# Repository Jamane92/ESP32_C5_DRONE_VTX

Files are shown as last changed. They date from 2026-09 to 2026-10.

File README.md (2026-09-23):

# ESP32_C5_DRONE_VTX

Ce projet à été réalisé individuellement en parallèle de mes études. C'est un module d'émission vidéo en digital à bas coût. Souhaitant me challenger dans mon parcours d'apprentissage en conception hardware, je me suis lancé le défi de construire un drone moi même, avec en première étape de ce gros projet, de faire un VTX ainsi qu'un Flight Controler (FC) de A à Z. Le projet Flight Controler est disponible sur cette page : https://github.com/Jamane92/Flight_Controler_STM32F405RGT6. 

Qu'est ce qu'un module VTX ? C'est un module d'émission vidéo, qui permet de transmettre la vue à la première personne du drone sur un écran au sol, que ce soit un téléphone ou un ordinateur par exemple. Cela permet de repérer le drone dans l'espace et de le faire voler à des endroits où nous ne pouvons pas voir. Un set complet bas/milieu de gamme coùute aux alentours de 200 à 250€. Ca fait mal. J'ai donc décidé, pour m'apprendre à implémenter une chip ESP32 sur PCB, de faire un PCB custom qui intègre une ESP32-C5-WROOM-1U-N8R8, une OV5640 ainsi qu'une carte SD, pour la somme ≈ 40€. Ce qui est un prix imbattable, tout simplement.

Le but de se projet est simple : d'un point de vue technique, m'apprendre à router des SoC (System On Chip) ainsi que des signaux critiques comme ceux de la caméra OV5640, le tout sur mon premier PCB 4 couches avec des composants SMD. Un grand pas donc depuis mon premier PCB sur mon robot équilibriste (https://github.com/Jamane92/Self_Balancing_Robot). Plus de détail dans les rubriques sur les choix de design (notamment sur des améliorations possibles).

Voilà à quoi ressemble le module : 
<p align="center">
vtx
</p>

Plus en détail, le coeur au milieu, à gauche l'antenne Lollipop et à droite la caméra. Ce PCB à fonctionné du premier coup. Voici à quoi ressemble l'interface WEB : 
<p align="center">
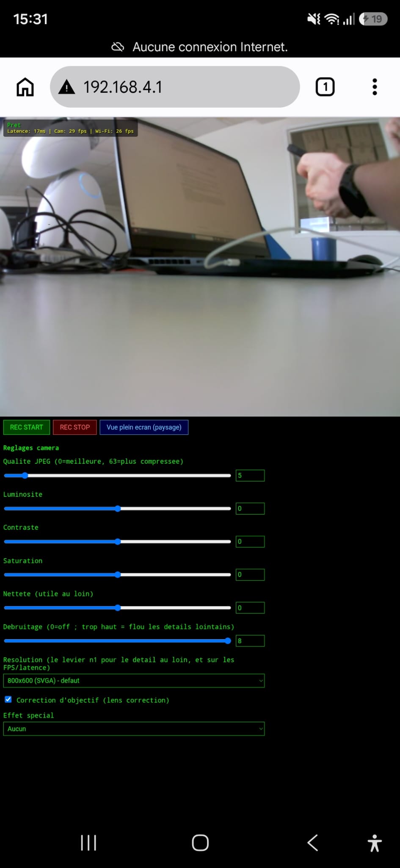
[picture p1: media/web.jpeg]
  
</p>

Voici un petit exemple de ce dont il est capable (entre autres : réglage de a qualité vidéo, compression, luminosité, saturation, contraste, filtre, enregistrement sur la SD Card) :

Voici une vidéo de mon balcon, au 3ème étage, avec l'exploration de tous les settings de la caméra : 

Voici une vidéo de moi en HVGA (480 × 320), gardez à l'esprit que l'on filmera en SVGA (800 × 600), soit littéralement 3 fois plus de pixels. 
<p align="center">
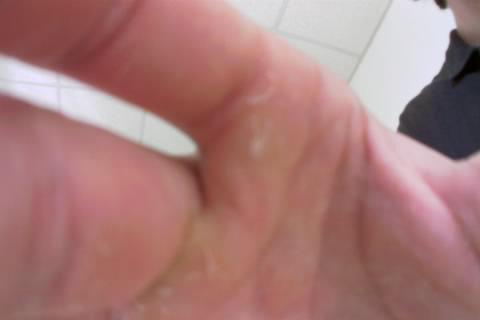
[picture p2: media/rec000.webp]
  
</p>

Pour la démo en vol, il faudra attendre que le projet du flight controler (https://github.com/Jamane92/Flight_Controler_STM32F405RGT6) soit terminé. 

Pour voir les performances du montage, voir le folder dedié.

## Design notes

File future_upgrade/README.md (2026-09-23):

Pour pénétrer des environnements denses (bâtiments, forêts), l'amélioration envisagée est matérielle : ajouter un **amplificateur de signal (LNA/PA)** entre l'ESP32 et l'antenne Lollipop.

L'impact de l'augmentation des Watts : Augmenter la puissance TX (par exemple passer de 50 mW à 1 Watt) n'empêche pas le signal d'être bloqué par un obstacle, mais lui donne une "force de frappe" bien supérieure. Si un mur absorbe -15 dBm du signal, un signal partant à +30 dBm (1 Watt) traversera le mur en conservant +15 dBm de l'autre côté, permettant à la puce RTL8812Au de continuer à recevoir le flux vidéo sans coupure.

Voici un exemple d'amplificateur avec un gain de 20 dB, de 28mm x 23mm :

<p align="center">
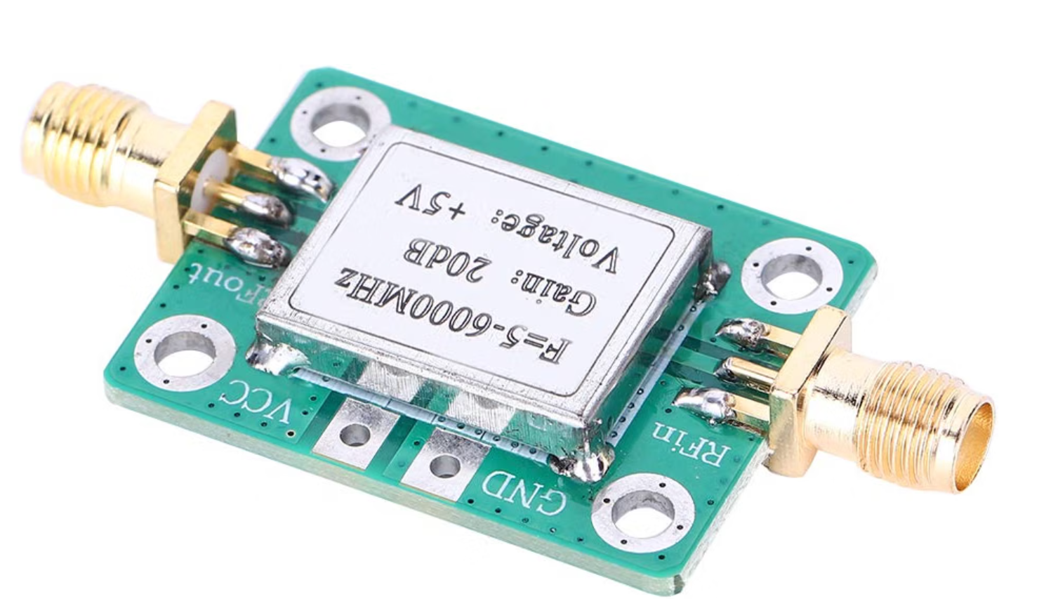
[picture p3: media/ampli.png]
Schématique

</p>

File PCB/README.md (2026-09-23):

Ce PCB contient **4 couches**, étant embarqué sur un drone, il possède des entrées d'alimentations **+5V**, que sont l'**USB-C**, également utilisé pour programmer l'**ESP32**, ainsi que des PADs de cuivre, qui viendront directement être branché à partir de mon flight controler. Il possède deux diodes Schottky pour faire du **OR'ing**. Une **OV5640**, un lecteur de **carte SD**, ainsi qu'un **module 1U** spécialement choisi pour la possibilité d'y brancher une **antenne**, qui est une **lollipop** en RHCP, mieux qu'une antenne "simple", car celle-ci émettra un signal en forme de cercle, parfaitement adapté pour une antenne en hauteur qui va communiquer avec le sol.

Je suis parti sur un **4 couches** pour me simplifier la vie. Mon stack-up est le suivant : 

  - L1 : SIGNAL
  - L2 : GND
  - L3 : GND
  - L4 : SIGNAL/POWER

Tous les composants sont sur la même face pour des raisons économiques (plus cher de faire les deux face lors de l'assemblage chez JLCPCB). 

Afin d'optimiser l'**intégrité des signaux**, de nombreux vias de masse (ground vias) ont été placés pour relier **(stitching)** les plans de masse entre les couches L2 et L3. Ce **stitching de masse assure un chemin de retour court**, direct et ininterrompu pour les signaux numériques à haute vitesse (bus de la caméra OV5640, interface de la carte SD) ainsi que pour la section RF à 5.8 GHz. Cela permet de **minimiser l'inductance des boucles de courant** et de **réduire drastiquement les interférences électromagnétiques** (EMI), un point absolument **critique** dans l'environnement très bruyant d'un drone (ESC, moteurs). 

L'**impédance** de la ligne de communication différentiel D+/D- est **matché à 90Ω**

Voici la schématique : 
<p align="center">
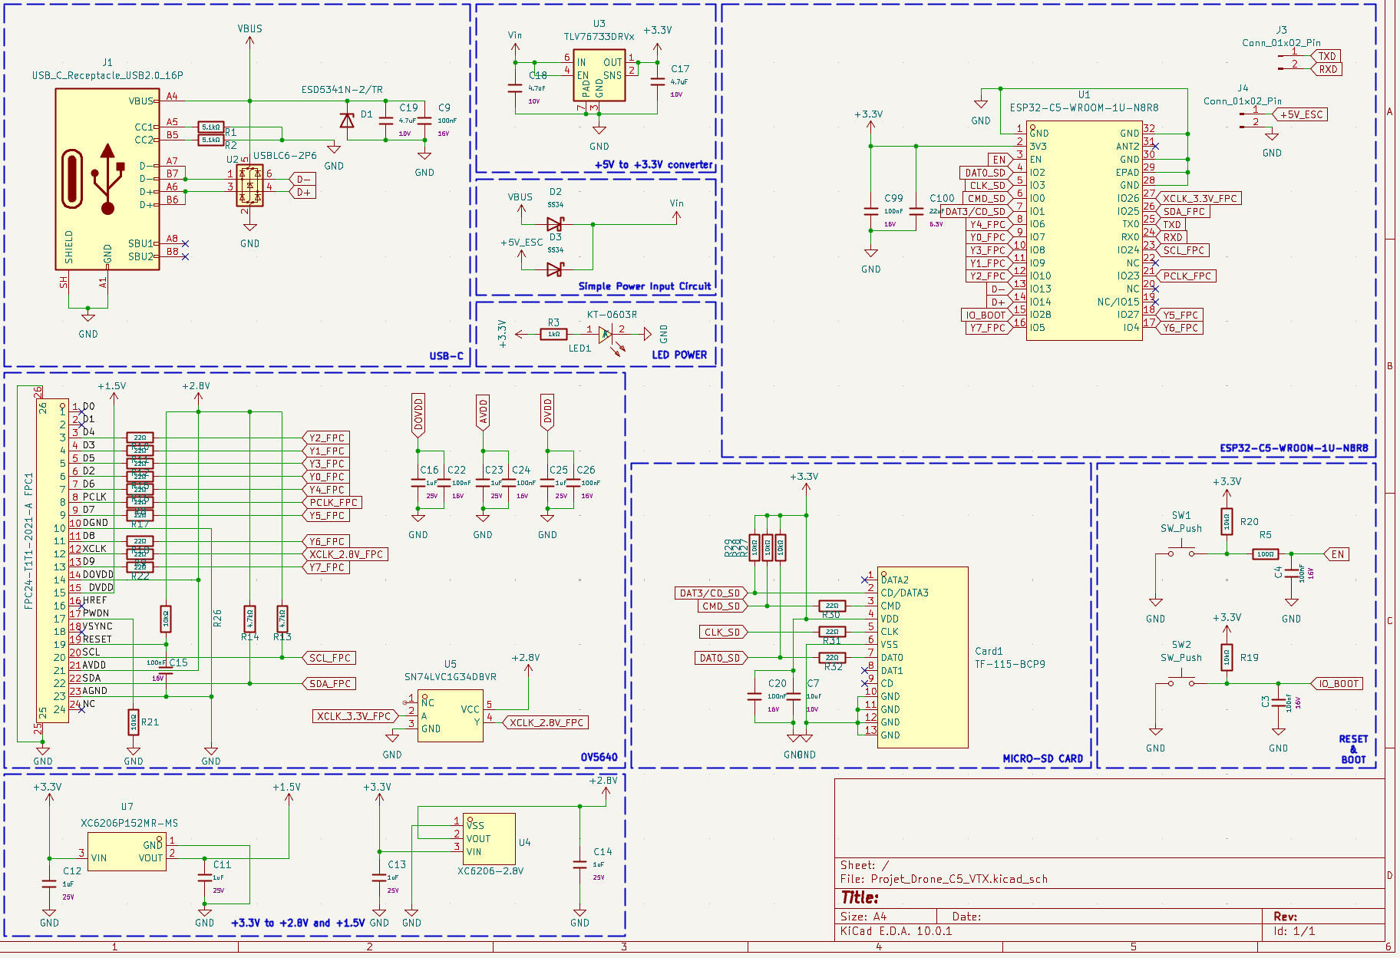
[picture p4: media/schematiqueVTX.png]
Schématique

</p>

Voici le routage : 
<p align="center">
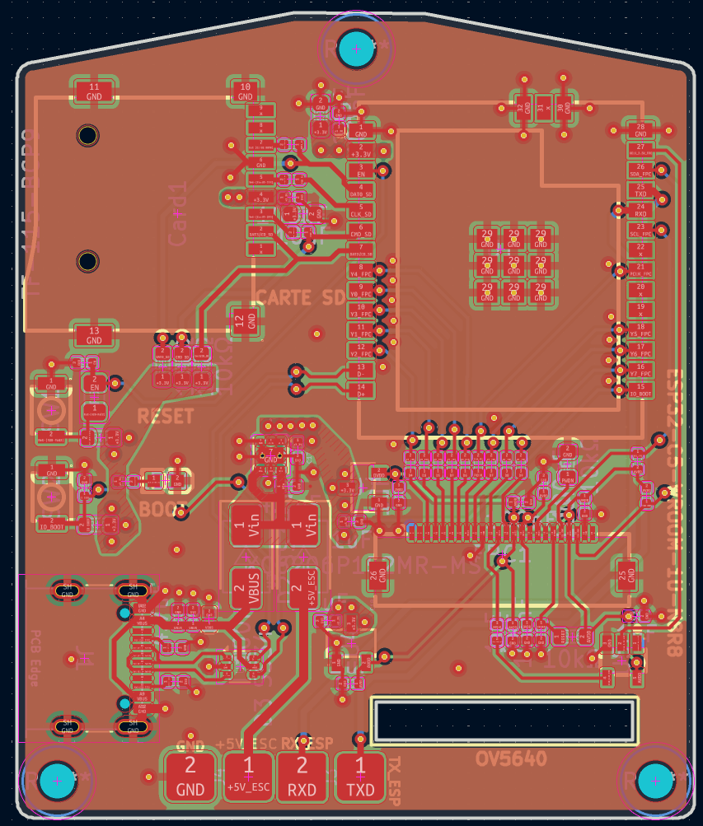
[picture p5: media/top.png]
top

</p>
<p align="center">
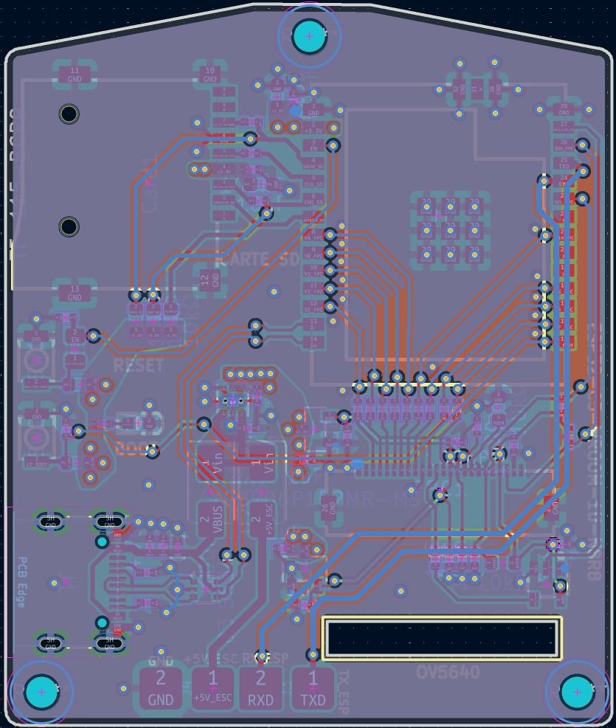
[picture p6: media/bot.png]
bot

</p>

Voici la 3D : 
<p align="center">
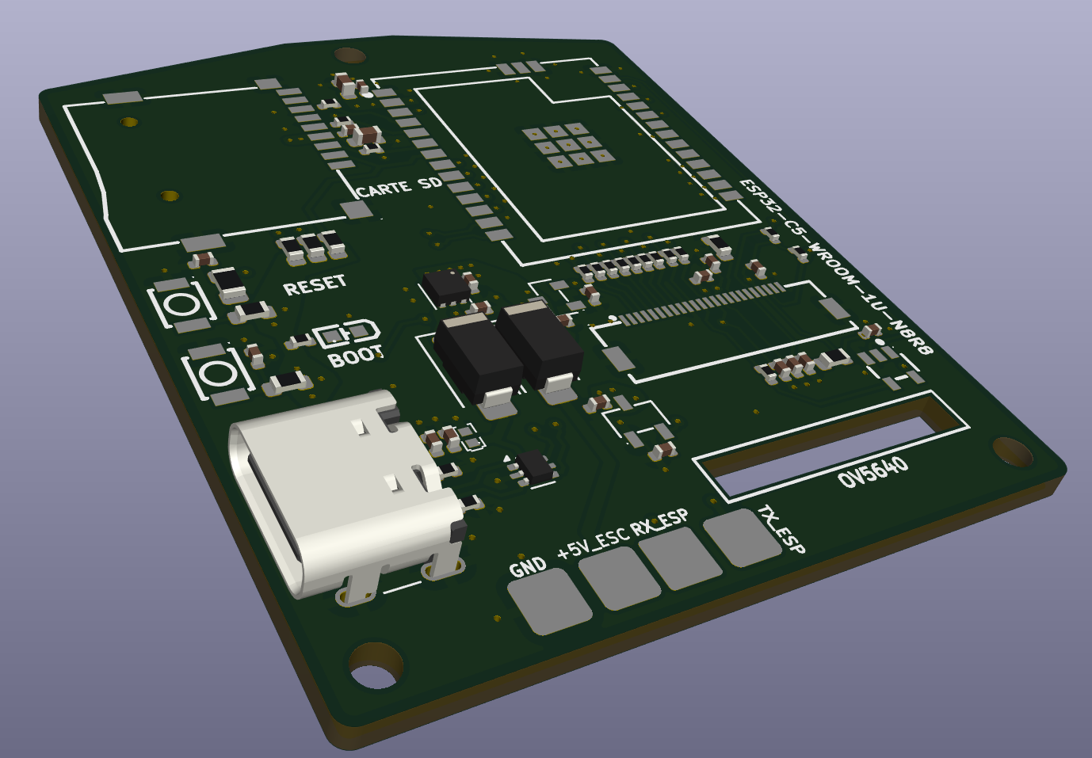
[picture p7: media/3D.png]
3D

</p>

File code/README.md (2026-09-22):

# VTX ESP32-C5 — Air unit FPV (caméra OV5640 + enregistrement SD + WiFi 5 GHz)

Firmware ESP-IDF pour un ESP32-C5 qui capture le flux JPEG d'une caméra OV5640
en DVP, le diffuse en direct via WiFi 5 GHz (softAP), l'enregistre en option
sur carte micro-SD, et expose une interface web de réglage (résolution,
qualité JPEG, netteté, etc.).

## Sommaire

- [Matériel et brochage](#matériel-et-brochage)
- [Pourquoi VSYNC/HREF ne sont pas câblés (et comment on s'en passe)](#pourquoi-vsynchref-ne-sont-pas-câblés-et-comment-ons-en-passe)
- [PARLIO : le périphérique qui reçoit le bus caméra](#parlio--le-périphérique-qui-reçoit-le-bus-caméra)
- [PSRAM : ce qui y vit et pourquoi](#psram--ce-qui-y-vit-et-pourquoi)
- [Modèle de tâches / concurrence](#modèle-de-tâches--concurrence)
- [Serveur HTTP et endpoints](#serveur-http-et-endpoints)
- [Structure du dépôt](#structure-du-dépôt)
- [Limitations connues](#limitations-connues)

## Matériel et brochage

- MCU : **ESP32-C5** (RISC-V, WiFi 2,4/5 GHz, un seul cœur pour les tâches applicatives)
- Caméra : **OV5640** (5 MP, DVP 8 bits, JPEG matériel), objectif M12 3,6 mm fixe
- Stockage : carte micro-SD en **SPI** (pas SDMMC 4 bits)

| Signal caméra | GPIO | Remarque |
|---|---|---|
| XCLK | 26 | Horloge fournie à la caméra (24 MHz) |
| SDA / SCL | 25 / 24 | I2C (SCCB) pour la configuration du capteur |
| D0-D7 | 7,9,10,8,6,27,4,5 | Bus de données parallèle 8 bits |
| PCLK | 23 | Horloge pixel — **seul signal de synchro réellement utilisé** |
| PWDN / RESET | -1 / -1 | Non câblés (tirés au bon niveau sur le module caméra) |
| **VSYNC** | **-1** | **Non câblé** |
| **HREF / HSYNC** | **-1** | **Non câblé** |

## Pourquoi VSYNC/HREF ne sont pas câblés (et comment on s'en passe)

Deux raisons se cumulent, une contrainte matérielle et un choix de brochage :

1. **VSYNC n'est de toute façon pas exploitable par le périphérique PARLIO
   de l'ESP32-C5.** Ce n'est pas qu'un manque de broches disponibles : même
   configuré, le driver logue *"VSYNC signal can not be used, ignoring the
   assigned pin"* — le contrôleur PARLIO RX de ce SoC n'a pas d'entrée
   dédiée à un signal de trame comme VSYNC.
2. **HREF/HSYNC auraient pu être câblés** (PARLIO sait s'en servir comme
   signal de "valid" matériel pour délimiter chaque ligne), mais l'ESP32-C5
   dispose de très peu de GPIO comparé à un ESP32/ESP32-S3 classique. Une
   fois XCLK, I2C, PCLK, les 8 lignes de données et les 4 broches SPI de la
   carte SD posées, il ne restait plus de broches à sacrifier pour HREF —
   d'où le choix de ne pas le câbler non plus.

**La solution retenue : laisser PARLIO tourner en mode "délimiteur
logiciel"** (`parlio_rx_soft_delimiter`), sans aucun signal de synchro
matériel. Le composant caméra échantillonne en continu les 8 lignes de
données sur chaque front de PCLK, produisant un flux d'octets brut, sans
notion native de "début/fin d'image".

Ça ne fonctionne que parce que **le capteur est configuré en sortie JPEG
matérielle** (`pixel_format = ESP_CAM_IO_PARL_PIXFORMAT_JPEG`). Le JPEG
est un format auto-délimité : chaque image commence par le marqueur SOI
(`0xFFD8`), puis un marqueur SOS (`0xFFDA`) avant les données entropiques,
et se termine par EOI (`0xFFD9`). Le driver fait tourner une petite machine
à états (`IDLE → HEADER → ENTROPY → IDLE`) sur le flux brut pour repérer
ces marqueurs et reconstituer les images, **entièrement en logiciel**, sans
avoir besoin de savoir où commence/finit une ligne ou une trame au niveau
matériel.

Cette astuce a une contrepartie importante : **elle ne marche qu'en JPEG.**
Passer le capteur en sortie brute (YUV/RGB, sans compression) ne
fonctionnerait pas dans cette configuration, faute de marqueurs à détecter
dans le flux — il faudrait alors câbler au minimum HREF (voire VSYNC sur un
autre SoC qui le supporte) pour cadrer les lignes/trames matériellement.

## PARLIO : le périphérique qui reçoit le bus caméra

PARLIO (*Parallel IO*) est un périphérique récent d'Espressif (ESP32-C5,
C6, H2, P4...) qui remplace l'ancien contrôleur "I2S caméra" utilisé sur
ESP32/ESP32-S3. Ici il est configuré en réception (RX) sur 8 lignes de
données avec une horloge externe (`PARLIO_CLK_SRC_EXTERNAL`) calée sur le
PCLK de la caméra — c'est le capteur qui pilote le rythme d'échantillonnage,
pas l'ESP32. Les octets reçus sont livrés par paquets via un callback
(`on_partial_receive`), consommés par la machine à états JPEG décrite
ci-dessus, puis remis à disposition de l'application dans une file
(`esp_cam_io_parl_receive()`), une image complète à la fois.

## PSRAM : ce qui y vit et pourquoi

L'ESP32-C5 n'a que quelques centaines de Ko de RAM interne, largement
insuffisants pour stocker plusieurs images JPEG + les buffers HTTP de front.
Tout ce qui est volumineux ou peut varier en taille est donc alloué
explicitement en PSRAM (`MALLOC_CAP_SPIRAM`), jamais sur la pile :

- Le buffer d'image partagé entre la capture et le streaming
  (`shared_frame.buf`, jusqu'à 256 Ko)
- Les buffers de rendu HTML de la page principale (`head`/`tail` dans
  `root_get_handler`)

Ce dernier point vient d'un vrai bug corrigé en cours de route : ces
buffers HTML étaient initialement des variables locales (donc sur la pile
de la tâche du serveur HTTP, ~4 Ko par défaut) — largement dépassées par
une page de plusieurs Ko, ce qui provoquait un dépassement de pile et un
redémarrage en boucle dès qu'un client se connectait. Les mettre en PSRAM
(avec libération systématique, y compris sur les chemins d'erreur) a réglé
le problème sans dépendre de la taille de pile allouée au serveur.

## Modèle de tâches / concurrence

Une seule tâche, `capture_task`, est l'unique lectrice du flux caméra.
À chaque image reçue, dans l'ordre :

1. Copie vers `shared_frame` (protégée par mutex) — consommée par `/stream`
   et `/capture`.
2. Si un enregistrement est en cours, écriture bloquante (`fwrite`) sur la
   carte SD.

Conséquence assumée : **un enregistrement SD actif ralentit légèrement le
flux live**, puisque l'écriture SD (SPI, largement plus lente que de la
RAM) retarde la lecture de l'image suivante par la même tâche. C'est
volontairement simple (une seule source de vérité, pas de double
tamponnage) plutôt que découplé sur deux tâches + une file — un choix qui
pourrait évoluer si le compromis devient gênant.

## Serveur HTTP et endpoints

| Endpoint | Rôle |
|---|---|
| `GET /` | Page principale : flux vidéo, REC start/stop, tous les réglages caméra |
| `GET /pov` | Flux vidéo seul, pivoté pour un affichage en paysage |
| `GET /stream` | Flux MJPEG (`multipart/x-mixed-replace`), port 81 |
| `GET /capture` | Une image JPEG unique |
| `GET /quality?q=` | Qualité JPEG (0-63) |
| `GET /settings?...` | Luminosité, contraste, saturation, effet, netteté, débruitage, correction d'objectif |
| `GET /resolution?f=` | Change la résolution à chaud (QQVGA → HD) |
| `GET /status` | JSON : FPS capture/stream, état d'enregistrement |
| `GET /record/start`, `/record/stop` | Pilotage de l'enregistrement SD |

## Structure du dépôt

Le projet avance par étapes validées une à une, chaque dossier reprenant
le précédent en y ajoutant une brique :

```
01_sd_card_test/          Montage SD seul
02_wifi_5ghz_test/        SoftAP WiFi 5 GHz seul
03_camera_validate/       Caméra OV5640 seule (une capture)
04_camera_stream_5ghz/    Flux MJPEG en direct via WiFi
05_camera_record_sd/      + enregistrement SD, tâche de capture unique
06_camera_quality_tuning/ + réglages avancés, page /pov, résolution à chaud
```

## Limitations connues

- **Plafond de gain (gainceiling) volontairement absent.** Le driver OV5640
  utilisé (identique sur ce point au driver officiel Espressif
  `esp32-camera`) écrit l'indice brut (0-6) dans les registres `0x3A18`/
  `0x3A19`, alors que l'OV5640 y attend un code de gain sur ~10 bits. Le
  résultat plafonne le gain réel bien en dessous de 1x — l'image devient
  très sombre et ne récupère plus tant que le capteur n'est pas réinitialisé.
  Le contrôle a été retiré de l'interface et de l'API tant que cette
  fonction n'est pas réécrite avec les vraies valeurs de registre.
- **Objectif à mise au point fixe**, sans autofocus (pas de moteur voice-coil
  câblé) — la netteté au loin dépend uniquement de la résolution choisie et
  du réglage mécanique de l'objectif.
- **Le champ "Latence" affiché à l'écran mesure le temps d'aller-retour de
  l'appel `/status`**, pas la latence bout-en-bout réelle du flux vidéo
  (qui inclut l'encodage JPEG, la mise en file PARLIO et le rendu côté
  navigateur). À prendre comme un indicateur de réactivité du WiFi, pas
  comme une mesure de latence vidéo absolue.

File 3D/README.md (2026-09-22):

Le module ayant pour vocation à être branché sur une frame de drone générique, j'ai dû imprimer en 3D une pièce pour que celui-ci se monte coorectement sur la frame en carbone que j'ai commandé. Voici à quoi ressemble la pièce : 

Voici la référence de ma frame en carbone (c'est la plus générique qui existe) :

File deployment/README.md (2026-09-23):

Le projet de base fonctionne bien avec un téléphone, mais l'utilisation d'un VRX adapté peut augmenter énormément les performances du système. C'est pourquoi j'ai fait le choix d'utiliser un module de récéption wifi avec des antennes, que je vais connecter à mon ordinateur, pour augmenter non seulement la portée mais également la latence. Je vais utiliser une clé WIFI Kali Linux avec puce RTL8812AU, double bande 1200 Mbps, avec un adaptateur USB sans fil USB 3.0, avec double antenne 5 dBi. 

Plus en détail, 

**Amélioration de la Portée (Sensibilité et Signal)**

  **Monitor (Écoute passive)** : En Wi-Fi standard (mode Access Point ou Station), si le signal devient trop faible, le protocole abandonne et la connexion réseau se coupe brutalement. Sous Linux, la clé Wi-Fi est basculée en mode monitor : elle écoute aveuglément la fréquence 5.8 GHz sans chercher à s'associer au routeur     de l'ESP32. Tant que des ondes arrivent, elle les capte, prolongeant la portée utile de plusieurs centaines de mètres.

  **Dégradation fluide (Graceful Degradation)** : Au lieu d'avoir une image vidéo qui fige (freeze) d'un seul coup en limite de portée, le récepteur Linux accepte d'afficher des paquets incomplets ou corrompus. L'image va se pixeliser ou se déformer par blocs (un peu comme la neige en analogique), ce qui te laisse le temps 				de réagir et de faire demi-tour avant le failsafe.

  **Connectique pour antennes à haut gain** : Une clé Wi-Fi USB compatible (ex: chipsets Atheros ou Realtek) permet de visser des antennes directionnelles (Patch ou Hélicoïdale) qui, combinées à l'antenne Lollipop RHCP de ton drone, concentrent la réception sur une zone précise pour aller chercher le signal beaucoup plus loin.

**Optimisation des Performances (Latence et Fluidité)**

  **Suppression des Acquittements (No ACK / Retransmission)** : Le Wi-Fi TCP/UDP standard exige que le récepteur confirme la bonne réception de chaque paquet. S'il y a des interférences (les moteurs, les ESC), le paquet est retransmis, créant des pics de latence énormes. Avec un VRX Linux, le flux est envoyé en Broadcast      (diffusion pure). Si une trame vidéo est perdue, elle est simplement ignorée pour afficher la suivante immédiatement. La latence reste ainsi constante et ultra-faible, ce qui est vital pour le pilotage.

  **Correction d'Erreur (FEC - Forward Error Correction)** : Pour compenser l'absence de retransmission, les systèmes VRX intègrent des algorithmes de redondance. Le système reconstruit mathématiquement les bouts d'images manquants à la volée grâce aux données de parité, lissant le flux vidéo de ton OV5640 même lorsque la         liaison radio est parasitée.

Voici la clé utilisé, achetée à 19.99€ sur Aliexpress : 
<p align="center">
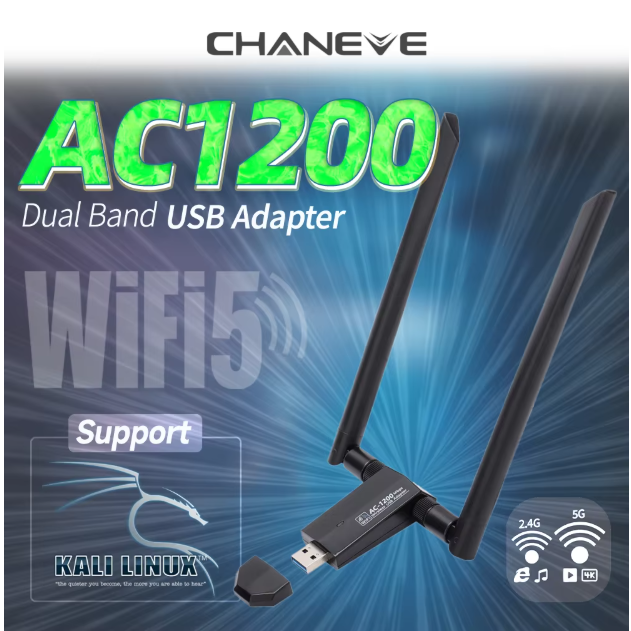
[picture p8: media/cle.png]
Schématique

</p>

On va ensuite dans Kali Linux, le script sera dispo dans cette partie du repo.

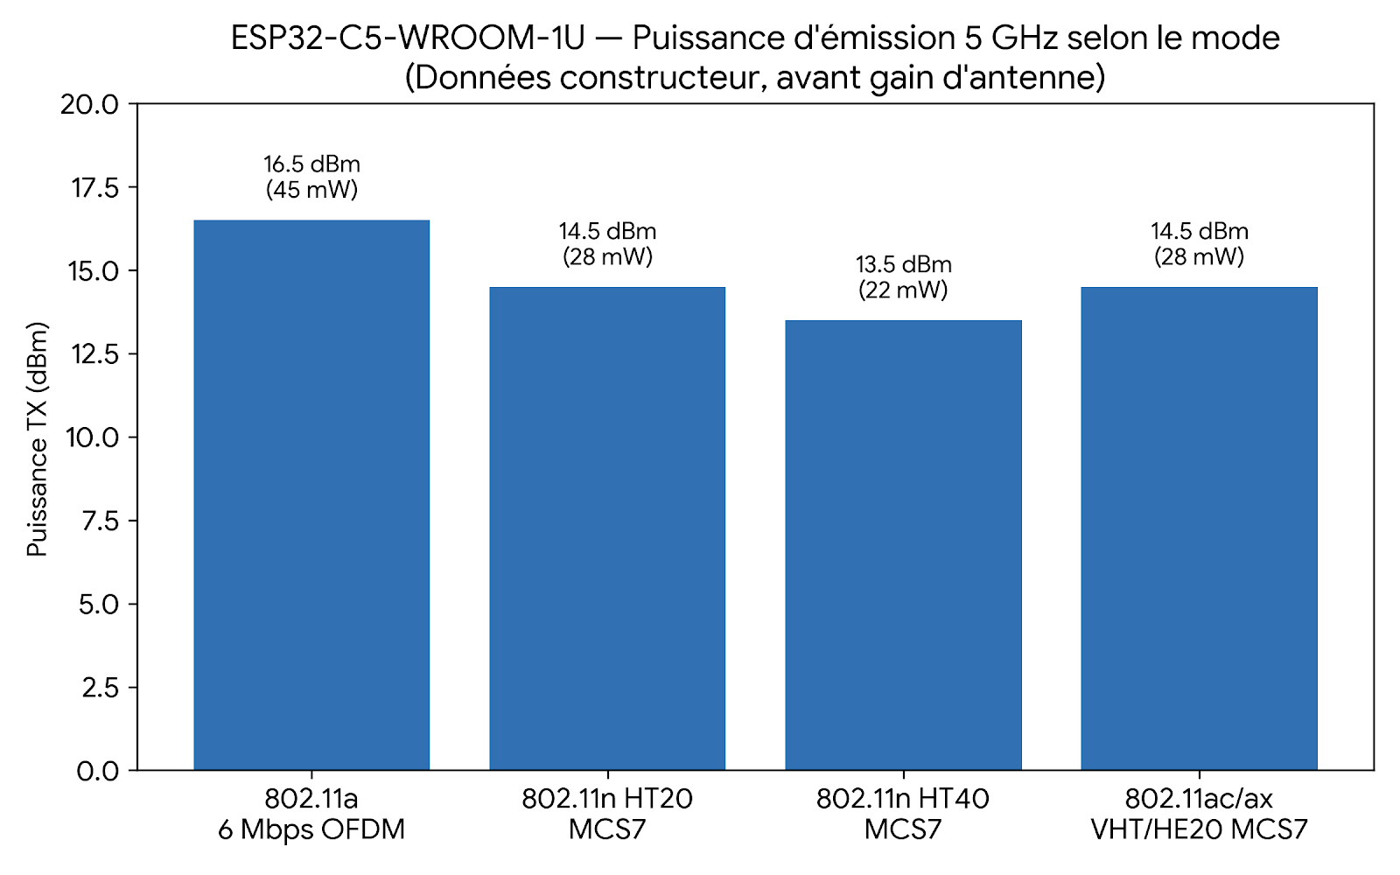
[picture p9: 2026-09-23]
media/Puissance_Emission.png

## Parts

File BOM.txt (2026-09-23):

1x OV5640 
1x 16 Gb SD Card 
1x lollipop antenna RHCP

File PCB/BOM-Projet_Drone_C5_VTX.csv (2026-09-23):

Comment | Designator | Footprint | LCSC | Quantity
100nF | C15,C20,C22,C24,C26,C3,C4,C9,C99 | C_0402 | C1525 | 9
100Ω | R5 | R_0805 | C17408 | 1
10kΩ | R19,R20,R21,R26,R27,R28,R29 | R_0603 | C25804 | 7
10uF | C7 | C_0603 | C19702 | 1
1kΩ | R3 | R_0402 | C11702 | 1
1uF | C11,C12,C13,C14,C16,C23,C25 | C_0402 | C52923 | 7
22uF | C100 | C_0603 | C59461 | 1
22Ω | R10,R11,R12,R15,R16,R17,R18,R22,R30,R31,R32,R8,R9 | R_0402 | C25092 | 13
4.7kΩ | R13,R14 | R_0402 | C25900 | 2
4.7uF | C17,C18,C19 | C_0402 | C23733 | 3
5.1kΩ | R1,R2 | R_0402 | C25905 | 2
ESD5341N-2/TR | D1 | DFN1006-2L-RD | C239773 | 1
ESP32-C5-WROOM-1U-N8R8 | U1 | COMM-SMD_32P-L21.2-W18.0_ESP32-C5-WROOM-1U | C51950748 | 1
FPC24-T1T1-2021-A | FPC1 | FPC-SMD_FPC24-T1T1-2021-A | C52740865 | 1
KT-0603R | LED1 | LED-SMD_L1.6-W0.8-R-RD | C2286 | 1
SN74LVC1G34DBVR | U5 | SOT-23-5_L2.9-W1.6-P0.95-LS2.8-BR | C840096 | 1
SS34 | D2,D3 | D_SMA | C8678 | 2
SW_Push | SW1,SW2 | KEY-SMD_B3U-1000PM | C231329 | 2
TF-115-BCP9 | Card1 | TF-SMD_TF-115-BCP9 | C720505 | 1
TLV76733DRVx | U3 | WSON-6-1EP_2x2mm_P0.65mm_EP1x1.6mm_ThermalVias | C2848334 | 1
USBLC6-2P6 | U2 | SOT-666 | C22390016 | 1
USB_C_Receptacle_USB2.0_16P | J1 | USB_C_Receptacle_GCT_USB4105-xx-A_16P_TopMnt_Horizontal | C5184243 | 1
XC6206-2.8V | U4 | SOT-23-3_L2.9-W1.6-P1.90-LS2.8-BR | C2892669 | 1
XC6206P152MR-MS | U7 | SOT-23-3_L2.9-W1.3-P1.90-LS2.4-BR | C30197512 | 1
Conn_01x02_Pin | J4 | SolderWire-0.127sqmm_1x02_P3.7mm_D0.48mm_OD1mm |  | 1
Conn_01x02_Pin | J3 | SolderWire-0.127sqmm_1x02_P3.7mm_D0.48mm_OD1mm |  | 1

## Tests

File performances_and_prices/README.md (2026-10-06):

# Analyse de Performance du Système Wi-Fi FPV / Télémétrie 📡

Ce document détaille les performances d'un système de transmission 100 % numérique basé sur un ESP32-C5 (TX), ses configurations de réception (RX) et son positionnement face au marché du FPV.

## 0. Consommation et performances vidéo

Le système consomme 5 V × 0,3 A = **1,5 W**.

Performances vidéo (à compléter avec des mesures réelles) :

| Résolution | Qualité JPEG | Taille moyenne d'une image | Images/s | Débit vidéo | Latence (caméra → écran) |
| :--- | :--- | :--- | :--- | :--- | :--- |
| QVGA 320×240 | _à mesurer_ | _à mesurer_ | _à mesurer_ | _à mesurer_ | _à mesurer_ |
| SVGA 800×600 | _à mesurer_ | _à mesurer_ | _à mesurer_ | _à mesurer_ | _à mesurer_ |

> La latence se mesure en filmant un chronomètre affiché à l'écran à côté de la caméra : la différence entre le chronomètre réel et celui affiché donne la latence totale.

## 1. Architecture du Système : Émission (VTX)

Le système est **numérique** et repose sur le Wi-Fi (802.11). Il utilise le **5 GHz sur le canal 36** (5180 MHz, soit 5170-5190 MHz), dans la sous-bande 5170-5250 MHz. En France, la décision ARCEP n° 2022-1960 autorise cette sous-bande pour les aéronefs sans équipage, avec une limite de **200 mW p.i.r.e.** (23 dBm).

**Matériel TX (drone) :**

* **Puce :** ESP32-C5-WROOM-1U (connecteur U.FL)
* **Antenne :** Lollipop 4 (gain 2,5 dBi, polarisation RHCP)

**Bilan de puissance (TX) :**
La puissance d'émission de la puce varie de 13,5 à 16,5 dBm (22 à 45 mW) selon le mode négocié. Avec le gain de l'antenne (2,5 dBi), la puissance rayonnée est de **16 à 19 dBm p.i.r.e. (environ 40 à 80 mW)**, ce qui reste sous la limite réglementaire de 23 dBm.

Le graphique montre que le mode **802.11a à 6 Mbps** est celui qui donne la puissance maximale (16,5 dBm) : c'est donc aussi le mode le plus favorable à la portée.

```mermaid
%%{init: {'themeVariables': {'xyChart': {'plotColorPalette': '#2ecc71'}}}}%%
xychart-beta
    title "ESP32-C5-WROOM-1U — Puissance d'émission brute 5 GHz"
    x-axis ["802.11a (6 Mbps)", "802.11n HT20", "802.11n HT40", "802.11ac/ax"]
    y-axis "Puissance TX (dBm)" 0 --> 20
    bar [16.5, 14.5, 13.5, 14.5]
```

## 2. Évolution de la Réception (VRX) et Portée

Le goulot d'étranglement de la version de base n'est pas le drone, mais la sensibilité du récepteur.

**Hypothèses du calcul :**
* Débit physique bas (~6 Mbps), seul débit pour lequel la sensibilité de −90 dBm est atteinte.
* Visibilité directe (LOS), propagation en espace libre.
* Portée « réelle » estimée = portée théorique ÷ 2,5 environ (sol, multitrajets, orientation des antennes). Pour un gain donné, le facteur ×4 en espace libre tombe plutôt vers ×2,5 en environnement réel.

| Configuration | Matériel VTX | Matériel VRX | Sensibilité RX | Portée théorique (LOS) | Portée réelle estimée |
| :--- | :--- | :--- | :--- | :--- | :--- |
| **Base (actuelle)** | ESP32-C5 + Lollipop 2,5 dBi | **Smartphone** | Faible (antennes internes) | ~ 230 m | **~ 90 m** |
| **Cible (améliorée)** | ESP32-C5 + Lollipop 2,5 dBi | **RTL8812AU (2× 5 dBi)** | Élevée (−90 dBm) | ~ 920 m | **~ 360 m** |

Remplacer le téléphone par une carte RTL8812AU avec antennes externes de 5 dBi ajoute environ **12 dB** au bilan de liaison. En espace libre, 12 dB multiplient la portée par 4, sans toucher au drone.

<div align="center">
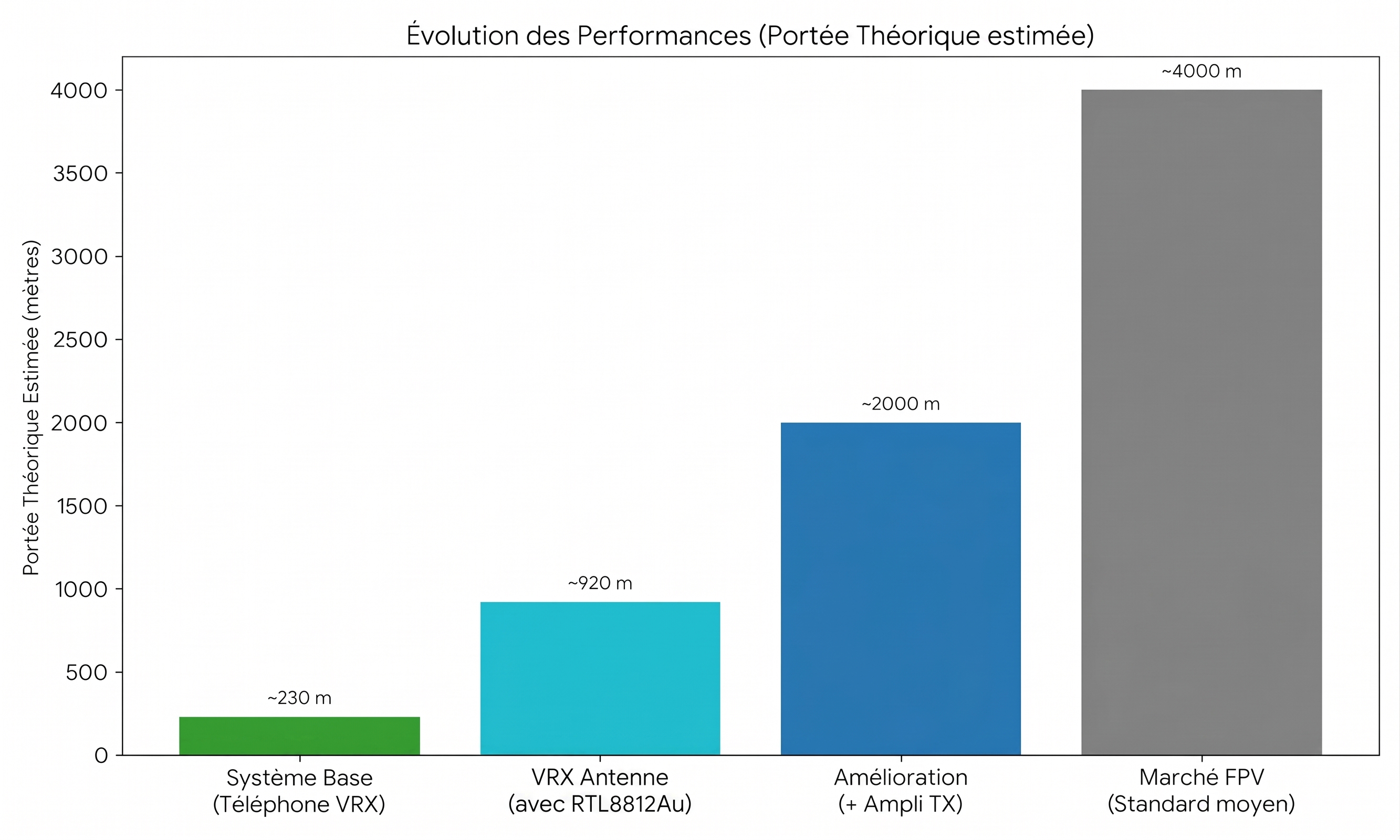
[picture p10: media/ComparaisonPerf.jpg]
Évolution des performances (portée théorique estimée)
  
</div>

**Limites à garder en tête :**

* **Le débit vidéo doit tenir dans le débit radio.** À 6 Mbps de débit physique, on dispose d'environ 4 à 5 Mbps utiles. Un JPEG SVGA de 30 Ko à 24 images/s représente déjà ~5,8 Mbps : il faut donc rester en résolution inférieure ou monter le débit radio, ce qui réduit la portée.
* **Polarisation.** L'antenne du drone est RHCP. Si les antennes de la clé RTL8812AU sont linéaires, la différence de polarisation coûte environ 3 dB (~30 % de portée). Pour profiter pleinement du gain, utiliser aussi des antennes RHCP en réception.

Je n'ai pas besoin de 4 km de portée : j'ai fait ce projet pour moi, et même divisée par 3, la portée réelle suffit largement pour mon application, comme pour la majorité des usages.

## 3. Pistes d'Amélioration Future : Amplification du Signal (TX)

Pour pénétrer des environnements denses (bâtiments, forêts), on peut ajouter un **amplificateur (PA/LNA)** entre l'ESP32 et l'antenne.

* **Version légale :** monter jusqu'à la limite de 23 dBm p.i.r.e. (200 mW) apporte environ **+4 à +7 dB** par rapport aux 16–19 dBm actuels, soit une portée théorique d'environ **1,7 km** (~ ×1,9).
* **Version 1 W (hors cadre) :** passer à 1 W apporte environ +12 dB (~ ×4, soit ~ 3,7 km théorique), mais sort du cadre réglementaire des 200 mW et demande plusieurs watts d'alimentation, contre 1,5 W pour le système actuel. Cette option n'est pas recommandée en France.
* **Effet sur les obstacles :** de la puissance en plus ne supprime pas l'atténuation d'un obstacle, mais laisse plus de marge. Si un mur atténue de 15 dB, un signal émis 12 dB plus fort arrive 12 dB plus fort de l'autre côté, ce qui peut suffire à maintenir la liaison.

## 4. Positionnement sur le Marché FPV (coût VTX + VRX)

La force du système est son coût global : contrairement aux systèmes du commerce où il faut acheter émetteur **et** récepteur (lunettes ou module), le VRX est ici soit gratuit (téléphone), soit très abordable (clé Wi-Fi sous Linux).

<div align="center">
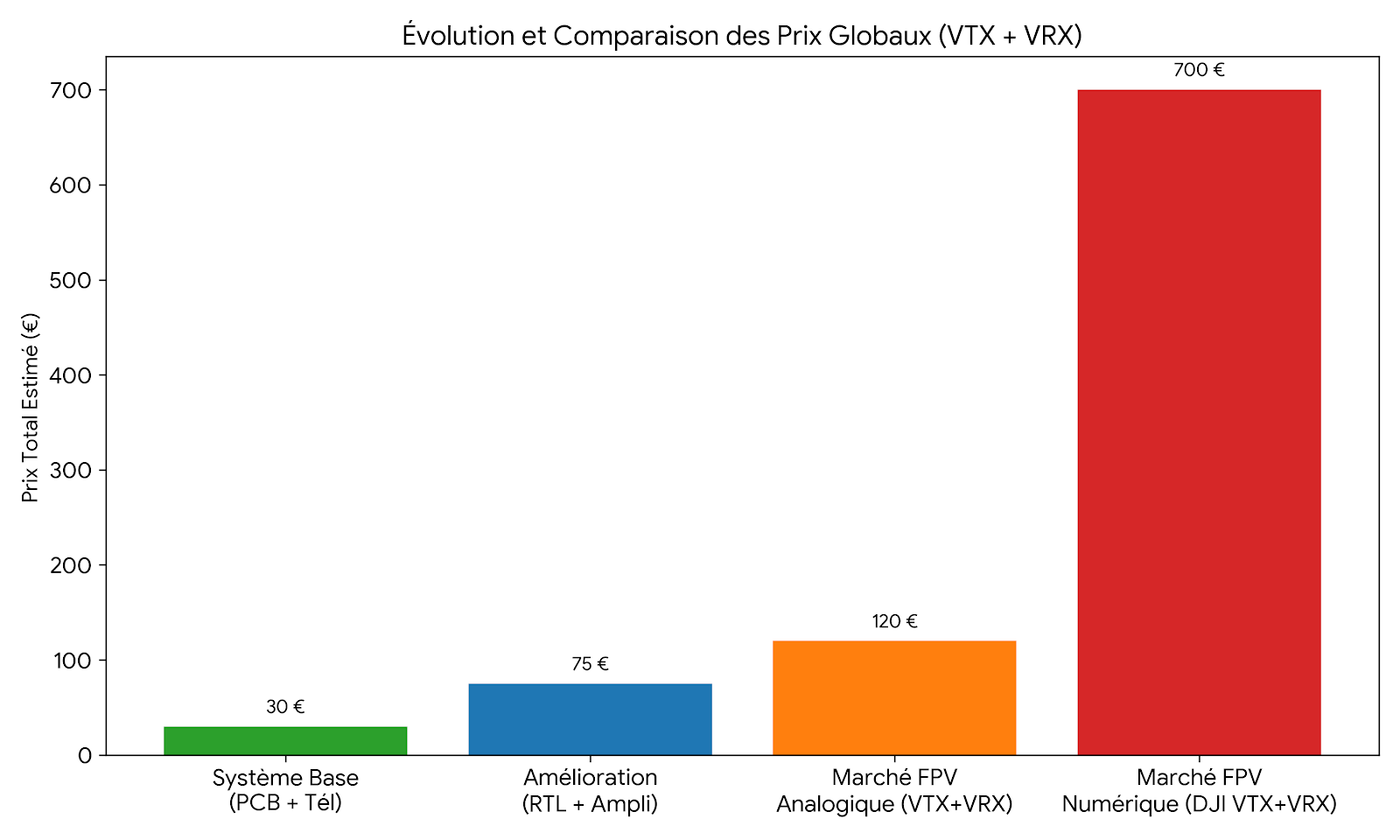
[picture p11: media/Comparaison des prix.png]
Comparaison des prix globaux (VTX + VRX)
  
</div>

### Portée théorique par euro investi

Les portées des systèmes du commerce sont des chiffres constructeurs en conditions idéales : elles ne sont pas directement comparables à une portée mesurée en France. Ces systèmes offrent en outre une image HD et des fonctions (DVR, etc.) que ce projet n'a pas.

| Système | Portée théorique | Prix total (VTX+VRX) | Ratio (m / €) |
| :--- | :--- | :--- | :--- |
| **Projet (upgrade légal 200 mW)** | **~ 1700 m** | **75 €** | **22,7 m / €** 🏆 |
| **Projet (cible, RTL8812AU)** | **~ 920 m** | **50 €** | **18,4 m / €** |
| Walksnail | ~ 4000 m | ~ 380 € | 10,5 m / € |
| Analogique | ~ 1000 m | ~ 100 € | 10,0 m / € |
| **Projet (base, smartphone)** | **~ 230 m** | **30 €** | **7,7 m / €** |
| DJI O3 | ~ 4000 m | ~ 800 € | 5,0 m / € |

**Conclusion :** pour 20 € de plus (50 € au total), la clé RTL8812AU multiplie la portée par 4 sur le papier et offre le meilleur rapport portée théorique / prix du tableau, avec une transmission numérique. Ce n'est pas un concurrent direct des systèmes HD du commerce : c'est une solution très économique, adaptée à une portée de quelques centaines de mètres.

## 5. Prochaines étapes

* Mesurer la taille des images, le débit et la latence (section 0).
* Passer à une réception sous Linux avec la RTL8812AU en mode moniteur.
* Remplacer le serveur HTTP/TCP par de l'injection de trames 802.11 brutes (sans association ni retransmissions), avec fragmentation des JPEG.
* Tester le débit radio fixe bas et mesurer la portée réelle sur le terrain.

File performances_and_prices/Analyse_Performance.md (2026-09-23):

# 📡 Analyse de Performance du Système Wi-Fi FPV / Télémétrie

Ce document détaille les performances du système de transmission 100% numérique basé sur un ESP32-C5 (TX), ses différentes configurations de réception (RX), et l'analyse de son positionnement face au marché du FPV.

## 1. Architecture du Système : Émission (VTX)

Le système est **numérique**, reposant sur les protocoles Wi-Fi (802.11). Il force l'utilisation du **5 GHz sur le canal 36** (5170-5250 MHz), une bande explicitement autorisée par l'ARCEP pour les drones avec une limite de 200 mW EIRP (Equivalent Isotropic Radiated Power).

**Matériel TX (Drone) :**

* **Puce :** ESP32-C5 WROOM 1U (avec connecteur U.FL)
* **Antenne :** Lollipop 4 (Gain : 2.5 dBi, Polarisation : RHCP)

**Calcul de puissance (Bilan de liaison TX) :**
La puissance d'émission brute de la puce (selon le mode négocié) varie de 13.5 à 16.5 dBm (22 à 45 mW).
En y ajoutant le gain de 2.5 dBi de l'antenne Lollipop, le système émet avec une puissance EIRP comprise entre **16 dBm et 19 dBm (soit environ 40 à 80 mW EIRP)**.

*Conclusion : Le système exploite une excellente antenne émettrice tout en restant parfaitement dans le cadre réglementaire français (max 23 dBm / 200 mW).*

```mermaid
%%{init: {'themeVariables': {'xyChart': {'plotColorPalette': '#2ecc71'}}}}%%
xychart-beta
    title "ESP32-C5-WROOM-1U — Puissance d'émission brute 5 GHz (Ton Matériel)"
    x-axis ["802.11a (6 Mbps)", "802.11n HT20", "802.11n HT40", "802.11ac/ax"]
    y-axis "Puissance TX (dBm)" 0 --> 20
    bar [16.5, 14.5, 13.5, 14.5]
```

## 2. Évolution de la Réception (VRX) et Portée

Le véritable goulot d'étranglement de la version de base n'est pas le drone (VTX), mais la sensibilité de l'appareil qui reçoit le signal (VRX).

| Configuration Globale | Matériel VTX (Drone) | Matériel VRX (Réception) | Sensibilité RX | Portée Théorique (LOS) | Portée Réelle (Estimée) | 
| :--- | :--- | :--- | :--- | :--- | :--- |
| **Système de Base (Actuel)** | ESP32-C5 + Lollipop 2.5 dBi | **Smartphone standard** | Mauvaise (Antennes internes) | \~ 230 m | **\~ 90 m** | 
| **Système Cible (Amélioré)** | ESP32-C5 + Lollipop 2.5 dBi | **VRX Antenne avec RTL8812Au (2x 5 dBi)** | Très haute (-90 dBm) | \~ 920 m | **\~ 360 m** | 

**Conclusion de l'amélioration RX :**
Remplacer le téléphone par la carte réseau avec puce RTL8812Au (et ses antennes externes 5 dBi) ajoute environ 12 dB au budget de liaison. En radiofréquence, un gain de 12 dB équivaut à **multiplier la portée par 4**. On gagne ainsi près de 690m de portée théorique sans rien modifier sur le drone.

<div align="center">
  Évolution des Performances (Portée Théorique estimée)
</div>

## 3. Piste d'Amélioration Future : Amplification du Signal (TX)

Pour pénétrer des environnements denses (bâtiments, forêts), l'amélioration envisagée est matérielle : ajouter un **amplificateur de signal (LNA/PA)** entre l'ESP32 et l'antenne Lollipop.

* **L'impact de l'augmentation des Watts :** Augmenter la puissance TX (par exemple passer de 50 mW à 1 Watt) n'empêche pas le signal d'être bloqué par un obstacle, mais lui donne une "force de frappe" bien supérieure. Si un mur absorbe -15 dBm du signal, un signal partant à +30 dBm (1 Watt) traversera le mur en conservant +15 dBm de l'autre côté, permettant à la puce RTL8812Au de continuer à recevoir le flux vidéo sans coupure.

* *Note : Cette modification fait sortir le système du cadre réglementaire des 200 mW (canal 36).*

## 4. Positionnement sur le Marché FPV (Coût VTX + VRX Complet)

La grande force de ce système est son coût global. Contrairement aux systèmes FPV du commerce où il faut acheter à la fois l'émetteur (Air Unit) ET le récepteur (Lunettes ou module), ici, le VRX est soit gratuit (téléphone), soit très abordable (Clé Wi-Fi Linux).

<div align="center">
  Évolution et Comparaison des Prix Globaux (VTX + VRX)
</div>

### Le Ratio Ultime : Portée Théorique gagnée par Euro investi

Si l'on croise le prix du système complet avec la portée théorique estimée, le projet sous RTL8812AU offre de loin la meilleure rentabilité du marché, battant même l'analogique d'entrée de gamme.

| Système | Portée Théorique | Prix Total (VTX+VRX) | Ratio (Mètres par Euro) | 
| :--- | :--- | :--- | :--- |
| **Ton Projet (Cible avec RTL8812Au)** | **\~ 920 m** | **54 €** | **17.0 m / €** 🏆 | 
| Marché Walksnail | \~ 4000 m | \~ 380 € | 10.5 m / € | 
| Marché Analogique | \~ 1000 m | \~ 100 € | 10.0 m / € | 
| **Ton Projet (Base)** | **\~ 230 m** | **30 €** | **7.6 m / €** | 
| Marché DJI O3 | \~ 4000 m | \~ 800 € | 5.0 m / € | 

**Conclusion Générale :**
En investissant 24€ supplémentaires dans un système "VRX Antenne avec RTL8812Au" pour la réception, le système devient le plus compétitif du marché en termes de rapport portée/prix. Il surpasse les solutions analogiques d'entrée de gamme, tout en offrant une transmission 100% numérique à un coût total (54€) infiniment plus bas que les géants du secteur.

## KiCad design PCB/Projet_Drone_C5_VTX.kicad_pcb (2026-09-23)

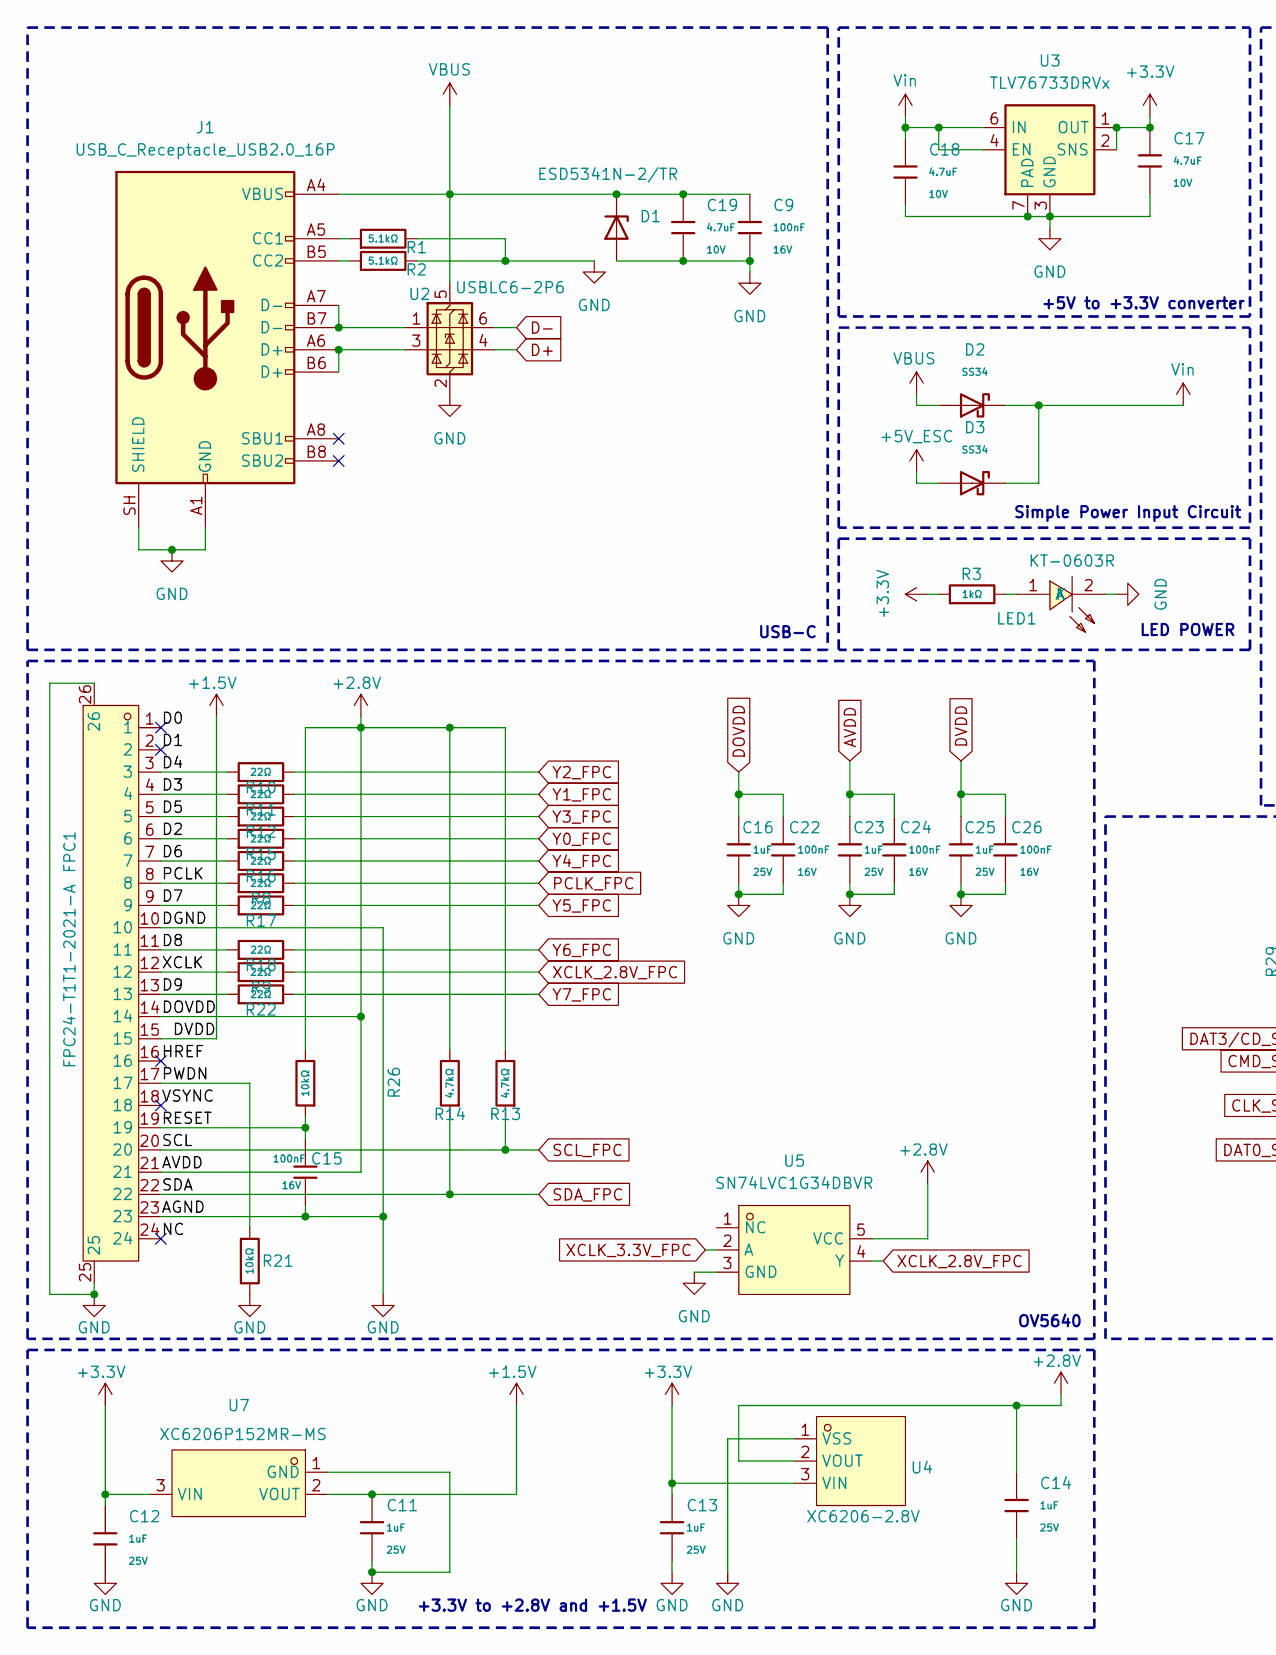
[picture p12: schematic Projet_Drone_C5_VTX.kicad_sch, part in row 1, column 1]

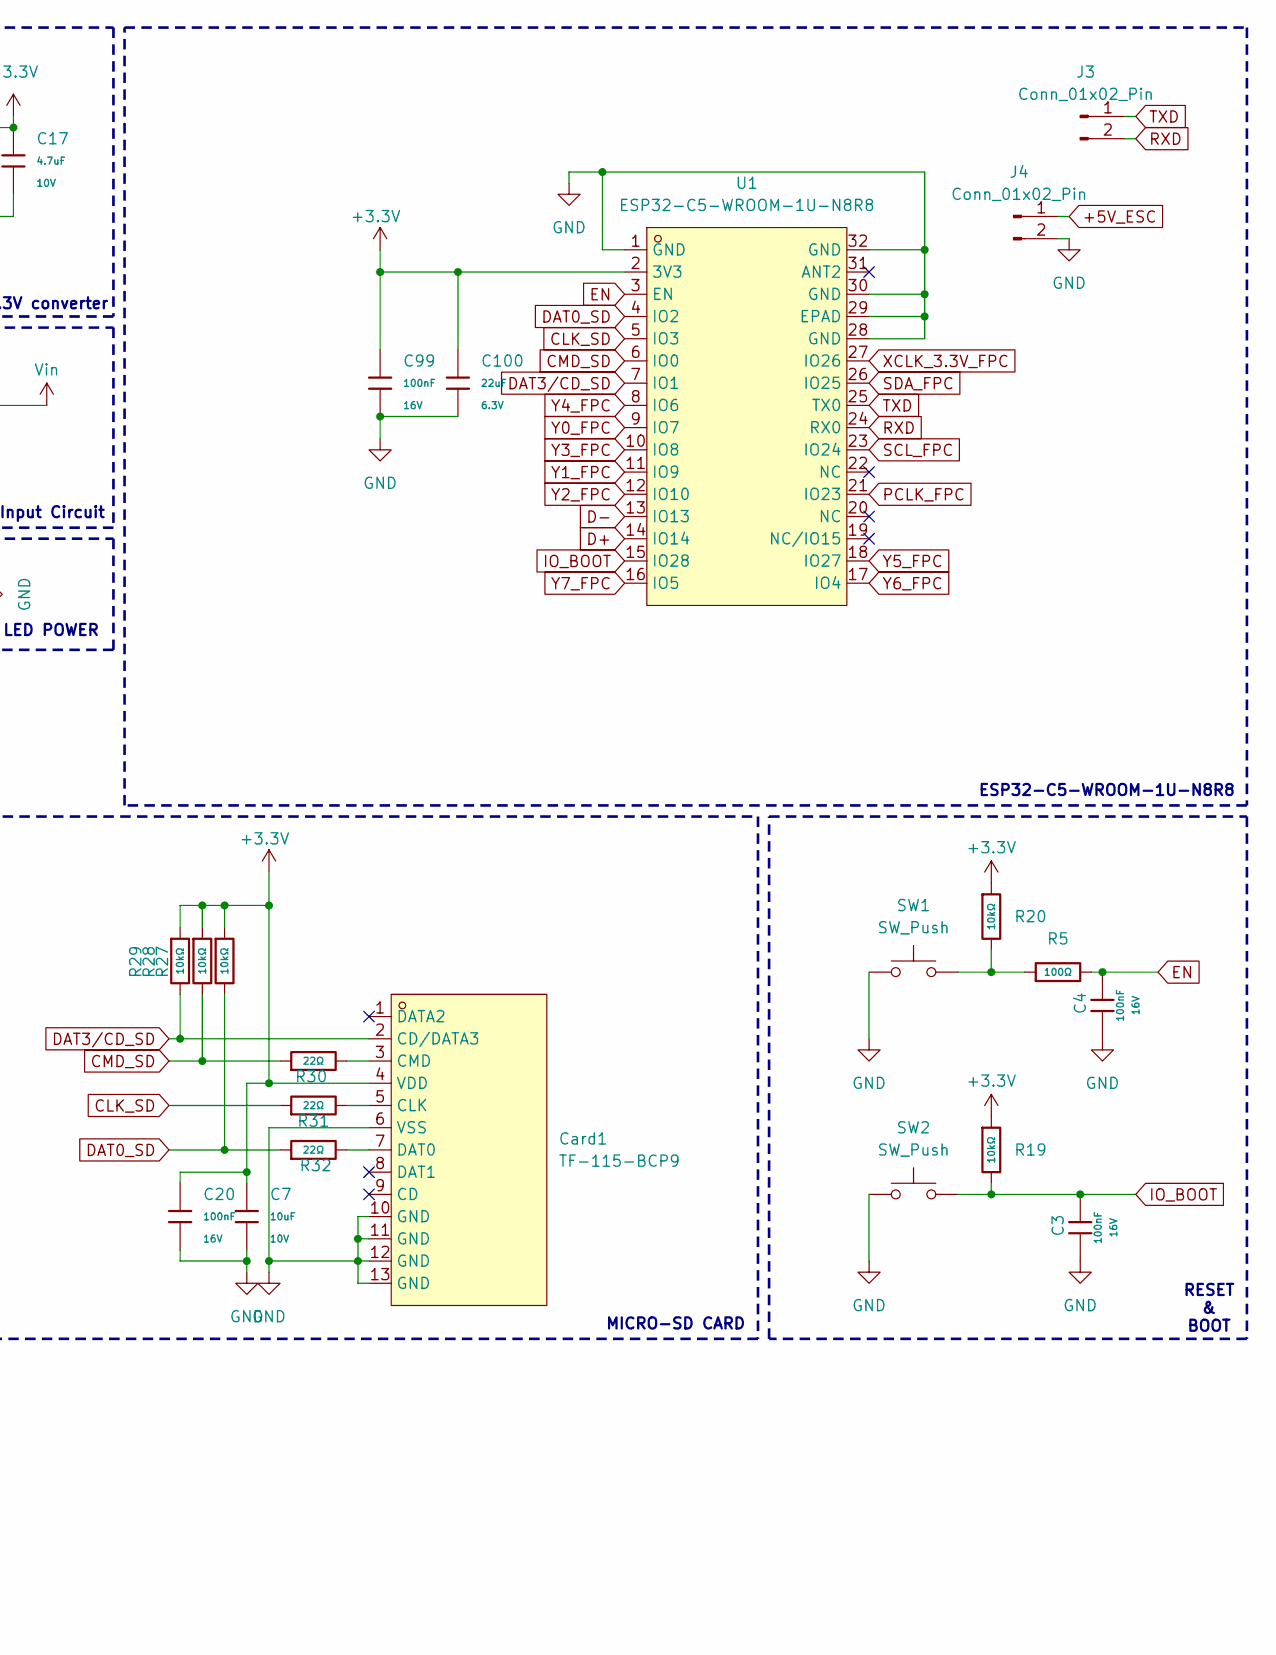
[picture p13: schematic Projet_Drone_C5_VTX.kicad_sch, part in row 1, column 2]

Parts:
C3, C4, C9, C15, C20, C22, C24, C26, C99: 100nF; C_0402; Voltage Rated 16V; Tolerance ±10%; Part CL05B104KO5NNNC; LCSC C1525
C7: 10uF; C_0603; Voltage Rated 10V; Tolerance ±10%; Part CL10A106KP8NNNC; LCSC C19702
C11, C12, C13, C14, C16, C23, C25: 1uF; C_0402; Voltage Rated 25V; Tolerance ±10%; Part CL05A105KA5NQNC; LCSC C52923
C17, C18, C19: 4.7uF; C_0402; Voltage Rated 10V; Tolerance ±20%; Part CL05A475MP5NRNC; LCSC C23733
C100: 22uF; C_0603; Voltage Rated 6.3V; Tolerance ±20%; Part CL10A226MQ8NRNC; LCSC C59461
Card1: TF-115-BCP9; TF-SMD_TF-115-BCP9; MPN TF-115-BCP9; LCSC Part C720505
D1: ESD5341N-2/TR; DFN1006-2L-RD
D2, D3: SS34; D_SMA; Forward Voltage (Vf@If) 550mV@3A; Reverse Voltage (Vr) 40V; Part SS34; LCSC C8678
FPC1: FPC24-T1T1-2021-A; FPC-SMD_FPC24-T1T1-2021-A; MPN FPC24-T1T1-2021-A; LCSC Part C52740865
J1: USB_C_Receptacle_USB2.0_16P; USB_C_Receptacle_GCT_USB4105-xx-A_16P_TopMnt_Horizontal
J3, J4: Conn_01x02_Pin; SolderWire-0.127sqmm_1x02_P3.7mm_D0.48mm_OD1mm
LED1: KT-0603R; LED-SMD_L1.6-W0.8-R-RD; MPN KT-0603R; LCSC Part C2286
R1, R2: 5.1kΩ; R_0402; Overload Voltage (Max) 50V; Tolerance ±1%; Part 0402WGF5101TCE; LCSC C25905
R3: 1kΩ; R_0402; Overload Voltage (Max) 50V; Tolerance ±1%; Part 0402WGF1001TCE; LCSC C11702
R5: 100Ω; R_0805; Overload Voltage (Max) 150V; Tolerance ±1%; Part 0805W8F1000T5E; LCSC C17408
R8, R9, R10, R11, R12, R15, R16, R17, R18, R22, R30, R31, R32: 22Ω; R_0402; Overload Voltage (Max) 50V; Tolerance ±1%; Part 0402WGF220JTCE; LCSC C25092
R13, R14: 4.7kΩ; R_0402; Overload Voltage (Max) 50V; Tolerance ±1%; Part 0402WGF4701TCE; LCSC C25900
R19, R20, R21, R26, R27, R28, R29: 10kΩ; R_0603; Overload Voltage (Max) 75V; Tolerance ±1%; Part 0603WAF1002T5E; LCSC C25804
SW1, SW2: SW_Push; KEY-SMD_B3U-1000PM
U1: ESP32-C5-WROOM-1U-N8R8; COMM-SMD_32P-L21.2-W18.0_ESP32-C5-WROOM-1U; MPN ESP32-C5-WROOM-1U-N8R8; LCSC Part C51950748
U2: USBLC6-2P6; SOT-666
U3: TLV76733DRVx; WSON-6-1EP_2x2mm_P0.65mm_EP1x1.6mm_ThermalVias
U4: XC6206-2.8V; SOT-23-3_L2.9-W1.6-P1.90-LS2.8-BR; MPN XC6206-2.8V; LCSC Part C2892669
U5: SN74LVC1G34DBVR; SOT-23-5_L2.9-W1.6-P0.95-LS2.8-BR; MPN SN74LVC1G34DBVR; LCSC Part C840096
U7: XC6206P152MR-MS; SOT-23-3_L2.9-W1.3-P1.90-LS2.4-BR; MPN XC6206P152MR-MS; LCSC Part C30197512

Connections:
+3.3V: C7.1, C12.1, C13.1, C17.1, C20.1, C99.1, C100.1, Card1.4 (VDD), R3.1, R19.1, R20.1, R27.1, R28.1, R29.1, U1.2 (3V3), U3.1 (OUT), U3.2 (SNS), U4.3 (VIN), U7.3 (VIN)
+5V_ESC: D3.2, J4.1
/D0: FPC1.1
/D1: FPC1.2
/D2: FPC1.6, R15.1
/D3: FPC1.4, R11.1
/D4: FPC1.3, R10.1
/D5: FPC1.5, R12.1
/D6: FPC1.7, R16.1
/D7: FPC1.9, R17.1
/D8: FPC1.11, R18.1
/D9: FPC1.13, R22.1
/HREF: FPC1.16
/NC: FPC1.24
/PCLK: FPC1.8, R8.1
/PWDN: FPC1.17, R21.1
/RESET: C15.1, FPC1.19, R26.1
/VSYNC: FPC1.18
/XCLK: FPC1.12, R9.1
AVDD: C14.1, C16.1, C22.1, C23.1, C24.1, FPC1.14, FPC1.21, R13.2, R14.2, R26.2, U4.2 (VOUT), U5.5 (VCC)
CLK_SD: R31.1, U1.5 (IO3)
CMD_SD: R28.2, R30.1, U1.6 (IO0)
D+: U1.14 (IO14), U2.4 (I/O2)
D-: U1.13 (IO13), U2.6 (I/O1)
DAT0_SD: R29.2, R32.1, U1.4 (IO2)
DAT3/CD_SD: Card1.2 (CD/DATA3), R27.2, U1.7 (IO1)
DVDD: C11.1, C25.1, C26.1, FPC1.15, U7.2 (VOUT)
EN: C4.1, R5.2, U1.3 (EN)
GND: C3.2, C4.2, C7.2, C9.2, C11.2, C12.2, C13.2, C14.2, C15.2, C16.2, C17.2, C18.2, C19.2, C20.2, C22.2, C23.2, C24.2, C25.2, C26.2, C99.2, C100.2, Card1.6 (VSS), Card1.10 (GND), Card1.11 (GND), Card1.12 (GND), Card1.13 (GND), D1.2 (A), FPC1.10, FPC1.23, FPC1.25, FPC1.26, J1.A1 (GND), J1.A12 (GND), J1.B1 (GND), J1.B12 (GND), J1.SH (SHIELD), J4.2, LED1.2 (K), R1.2, R2.2, R21.2, SW1.1, SW2.1, U1.1 (GND), U1.28 (GND), U1.29 (EPAD), U1.30 (GND), U1.32 (GND), U2.2 (GND), U3.3 (GND), U3.5 (GND), U3.7 (PAD), U4.1 (VSS), U5.3 (GND), U7.1 (GND)
IO_BOOT: C3.1, R19.2, SW2.2, U1.15 (IO28)
unnamed: Card1.5 (CLK), R31.2
unnamed: Card1.3 (CMD), R30.2
unnamed: Card1.7 (DAT0), R32.2
unnamed: J1.A5 (CC1), R1.1
unnamed: J1.B5 (CC2), R2.1
unnamed: J1.A6 (D+), J1.B6 (D+), U2.3 (I/O2)
unnamed: J1.A7 (D-), J1.B7 (D-), U2.1 (I/O1)
unnamed: LED1.1 (A), R3.2
unnamed: R5.1, R20.2, SW1.2
PCLK_FPC: R8.2, U1.21 (IO23)
RXD: J3.2, U1.24 (RX0)
SCL_FPC: FPC1.20, R13.1, U1.23 (IO24)
SDA_FPC: FPC1.22, R14.1, U1.26 (IO25)
TXD: J3.1, U1.25 (TX0)
VBUS: C9.1, C19.1, D1.1 (K), D2.2, J1.A4 (VBUS), J1.A9 (VBUS), J1.B4 (VBUS), J1.B9 (VBUS), U2.5 (VBUS)
Vin: C18.1, D2.1, D3.1, U3.4 (EN), U3.6 (IN)
XCLK_2.8V_FPC: R9.2, U5.4 (Y)
XCLK_3.3V_FPC: U1.27 (IO26), U5.2 (A)
Y0_FPC: R15.2, U1.9 (IO7)
Y1_FPC: R11.2, U1.11 (IO9)
Y2_FPC: R10.2, U1.12 (IO10)
Y3_FPC: R12.2, U1.10 (IO8)
Y4_FPC: R16.2, U1.8 (IO6)
Y5_FPC: R17.2, U1.18 (IO27)
Y6_FPC: R18.2, U1.17 (IO4)
Y7_FPC: R22.2, U1.16 (IO5)

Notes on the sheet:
MICRO-SD CARD
+5V to +3.3V converter
LED POWER
+3.3V to +2.8V and +1.5V
USB-C
ESP32-C5-WROOM-1U-N8R8
RESET & BOOT
Simple Power Input Circuit
OV5640

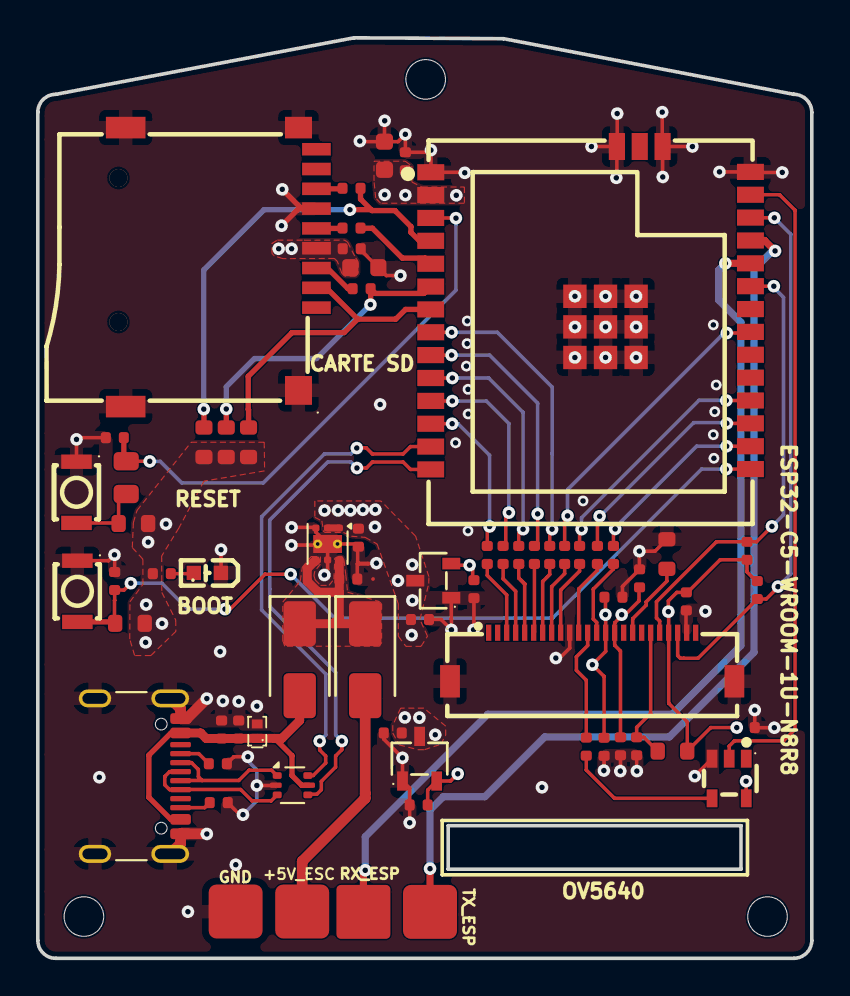
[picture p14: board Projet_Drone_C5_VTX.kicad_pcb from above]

Board: 4 copper layers, 43.0 x 51.1 mm, 64 parts (0 on the bottom side), 51 nets.

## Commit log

2026-09-23 Enhance README with PCB design details
    Added detailed description of PCB design and layout, including layer stack-up and signal integrity considerations.
2026-09-23 Update schematic and add routing images in README
    Updated schematic image link and added routing images.
2026-09-23 Change schematic image source to local file
    Updated the schematic image source in the README to a local path.
2026-09-23 Fix image syntax for VTX schematic in README
    Updated image syntax for schematic in README.
2026-09-23 Improve schematic image display in README
    Updated schematic image formatting and added alignment.
2026-09-23 Add new image to PCB README
    Added a new image to the README for better visualization.
2026-09-23 Clean up HTML tags in PCB README
    Removed unnecessary HTML paragraph tags around images in the README.
2026-09-23 Include 3D image in README
    Added a 3D image representation of the PCB.
2026-09-23 Add components to BOM file
2026-09-23 Correct investment amount for VRX Antenna system
    Updated the investment amount for the VRX Antenna system in the general conclusion.
2026-09-23 Update README with hardware enhancement details
    Added details on hardware improvements for dense environments and the impact of increasing transmission power.
